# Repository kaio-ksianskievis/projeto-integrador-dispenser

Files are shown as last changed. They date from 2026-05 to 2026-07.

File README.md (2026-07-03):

# 🚰 Precision Water Dispenser - IoT Edition

> **Projeto Integrador - Engenharia da Computação (UFSM)**

Sistema de controle e gestão de dispenser de precisão operando de forma autônoma. O projeto utiliza um **ESP32** atuando como Web Server embutido (Edge Computing), hospedando sua própria interface de usuário e controlando o hardware em tempo real sem a necessidade de um servidor back-end externo.

---

## Testes e Calibração da Bomba

Para garantir a precisão do dispenser, realizamos testes práticos variando a tensão e medindo o tempo de resposta da bomba. Os dados coletados de vazão, corrente e tempo estão consolidados na tabela abaixo:

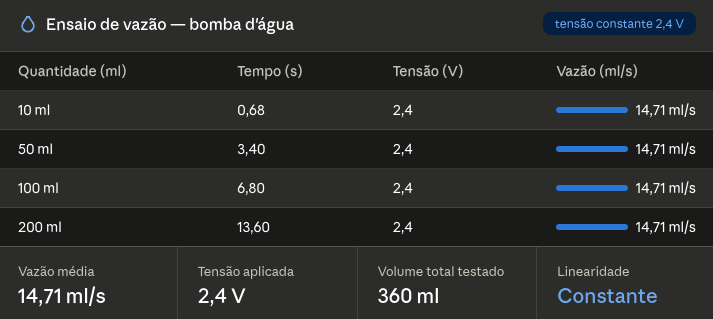
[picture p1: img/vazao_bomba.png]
Tabela de Calibração de Vazão


> **Nota de Engenharia:** Com base nesses testes, optamos por fixar a operação na tensão mínima de **2.4V** utilizando um módulo conversor Buck. Nessa faixa, a vazão oferece a melhor resolução para a matemática de controle de tempo no nosso firmware C++, minimizando o erro por inércia do motor e evitando transbordamentos.

---

## 📋 Sobre o Projeto

Este projeto foi arquitetado com foco na estabilidade elétrica e independência de rede, características essenciais para sistemas embarcados em apresentação.

### Principais Funcionalidades
* **Web Server Embutido:** A interface (HTML/CSS/JS) é hospedada diretamente na memória Flash do ESP32 utilizando `PROGMEM`, garantindo baixa latência e dispensando hospedagem externa.
* **Cálculo Dinâmico de Vazão:** O usuário insere a quantidade em mililitros (ml) via interface Web, e o JavaScript realiza a conversão em tempo de acionamento do relé com base no fator de calibração prático.
* **Isolação de Domínios de Energia:** Arquitetura de hardware projetada para isolar a alimentação do microcontrolador (5V lógico) da alimentação de força motriz (Bateria/Pilhas reguladas via LM2596), prevenindo resets por *brownout* devido ao pico de partida do motor.

---

## 🛠️ Stack Tecnológica

### Software (Firmware e Interface)
* **Linguagem Principal:** C/C++ (Arduino Core para ESP32)
* **Bibliotecas:** `WiFi.h`, `WebServer.h`
* **Front-end:** HTML5, CSS3, Vanilla JavaScript (Embutidos no C++)

### Hardware
* **Microcontrolador:** ESP32 (DevKit V1 / WROOM-32)
* **Atuador:** Bomba de Água RS 385 (Diafragma)
* **Chaveamento:** Módulo Relé 5V (1 Canal)
* **Regulação de Força:** Módulo Step-Down LM2596
* **Alimentação:** Fonte USB 5V (ESP32) + Suporte Independente de 4 Pilhas AA / Bateria de Lítio (Bomba)

---

## 🔧 Como Executar (Setup)

### 1. Montagem do Hardware (Atenção à Isolação)
Para reproduzir o projeto sem travamentos, respeite a separação de energia:
1. Conecte o **ESP32** na tomada via cabo USB (Pino `VIN` e `GND` alimentam a lógica do Relé).
2. Conecte a fonte de baterias isolada na entrada (`IN+` / `IN-`) do **LM2596**. Regule a saída para **2.4V**.
3. Use o pino **COM** e **NO** do Relé para chavear apenas o polo positivo que sai do LM2596 para a Bomba de Água. O `GND` da saída do LM2596 vai direto para a bomba.
4. O pino de sinal (`IN`) do Relé vai ao pino Digital `D4` do ESP32.

### 2. Configuração do Firmware
1. Abra o arquivo `.ino` ou `main.cpp` na IDE (Arduino IDE / PlatformIO).
2. Localize as variáveis de rede e insira as credenciais de um **Hotspot Móvel (2.4 GHz)** para contornar bloqueios de redes institucionais corporativas:
   ```cpp
   const char* ssid = "NOME_DO_SEU_HOTSPOT";
   const char* password = "SENHA";

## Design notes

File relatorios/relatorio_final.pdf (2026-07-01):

Dispenser de Líquidos — Relatório Final

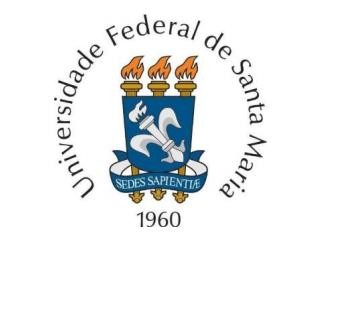
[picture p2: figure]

UNIVERSIDADE FEDERAL DE SANTA MARIA
Engenharia de Computação

# RELATÓRIO FINAL

## DISPENSER DE LÍQUIDOS

Sistema Automatizado de Dosagem com Controle Microcontrolado e Interface Web

Pedro Gomes
Leonardo Miotti
Breno Germano
Kaio Ksianskievis

Santa Maria, RS
2026

## 1. Introdução

Este documento consolida o relatório final do projeto Dispenser de Líquidos, desenvolvido pela equipe para a disciplina de Projeto Integrador do curso de Engenharia de Computação da UFSM. O trabalho evoluiu de uma proposta conceitual — um sistema automatizado de dosagem baseado no microcontrolador ESP32 — para um protótipo físico efetivamente montado, testado e ajustado em bancada.

Ao longo da implementação prática, diversas premissas do projeto original precisaram ser revistas a partir de evidência experimental: o componente hidráulico inicialmente escolhido não atendeu ao requisito de estanqueidade, e a topologia de alimentação elétrica planejada mostrou-se eletricamente inviável diante da corrente exigida pelos atuadores. Este relatório apresenta, de forma estruturada, o problema abordado, a solução proposta, o desenvolvimento realizado — incluindo as falhas técnicas identificadas e as respectivas ações corretivas — e os resultados obtidos até o momento.

## 2. Definição do Problema

O problema central reside na imprecisão e na falta de controle volumétrico em processos manuais de distribuição de líquidos. Em diversos contextos — desde o preparo de bebidas em escala comercial até o fracionamento de reagentes em laboratórios ou de insumos na agroindústria — a manipulação humana está sujeita a variações significativas (erro humano), o que resulta em desperdício de matéria-prima e falta de padronização no produto final.

Além disso, a ausência de monitoramento digital impede a coleta de dados sobre o consumo em tempo real. Sem uma interface de controle, torna-se inviável estabelecer dosagens exatas de forma repetitiva ou integrar essa tarefa a um ecossistema de Internet das Coisas (IoT), limitando a eficiência operacional e a rastreabilidade do processo.

Pontos-chave do problema:

- Variabilidade volumétrica: dificuldade em manter constância nas doses servidas manualmente.
- Ineficiência operacional: tempo gasto em medições manuais e retrabalho por erro.
- Falta de conectividade: inexistência de dados sobre o fluxo e o volume dispensado para fins de gestão e rastreabilidade.

## 3. Solução Proposta

A solução proposta consiste no desenvolvimento de um Sistema Automatizado de Dosagem com Controle Microcontrolado e Interface Web, fundamentado na integração de hardware e software para garantir precisão e facilidade de uso.

### 3.1. Arquitetura de Hardware

O núcleo do hardware é baseado no microcontrolador ESP32, escolhido por sua capacidade de processamento e conectividade Wi-Fi nativa. Ele é responsável por acionar a bomba dispensadora e por temporizar/medir a vazão de forma a garantir a dose exata configurada pelo usuário.

### 3.2. Arquitetura de Software

Para que a solução fosse completa e gerenciável, a arquitetura de software foi planejada em duas camadas, mantendo a proposta enxuta e compatível com o escopo da disciplina:

- Camada de Controle (Firmware): desenvolvida para o ESP32, responsável por gerenciar os periféricos de entrada e saída (sensores e atuadores) e por expor os comandos de dosagem através de requisições HTTP.
- Camada de Interface (HTML/CSS/JavaScript): interface web leve, servida diretamente pelo ESP32, que permite ao usuário selecionar a quantidade desejada e iniciar remotamente o processo de dosagem, sem a necessidade de um servidor de backend dedicado.

Optou-se por não utilizar uma camada de backend separada (como um servidor Java): a lógica de configuração de dose e o acionamento da bomba são tratados diretamente pelo firmware do ESP32, que também hospeda a página de interface. Essa simplificação reduziu a complexidade de integração e de infraestrutura necessária, mantendo o sistema autocontido em um único dispositivo.

### 3.3. Viabilidade Acadêmica

Essa abordagem é altamente viável para o contexto acadêmico, pois permite a aplicação de conceitos de Sistemas Operacionais de Tempo Real (RTOS), protocolos de comunicação (HTTP) e Engenharia de Software. O desenvolvimento foi planejado de forma modular: controle básico da bomba, seguido pela exposição de comandos via requisições HTTP e, por fim, a interface web em HTML/CSS/JavaScript — garantindo entrega contínua ao longo da disciplina.

## 4. Desenvolvimento Realizado

A fase de montagem e testes práticos do subsistema hidráulico e do subsistema de potência revelou necessidades de ajustes mecânicos e eletrônicos essenciais para o funcionamento correto e seguro do dispositivo. Esta seção descreve, de forma técnica, cada etapa da implementação, os problemas identificados e as ações corretivas adotadas.

### 4.1. Subsistema Hidráulico: Seleção e Substituição da Bomba

Nos testes funcionais de bancada para homologação dos atuadores, a equipe montou e avaliou operacionalmente uma motobomba submersível/in-line (Bomba 1). Os ensaios práticos revelaram uma inconformidade crítica no comportamento dinâmico do fluido: após o corte da alimentação elétrica do motor, o componente falhou em interromper o fluxo ("não parava a água"). Essa ausência de estanqueidade passiva gerava gotejamento contínuo e fluxo residual por gravidade/sifonagem, o que comprometia totalmente o requisito de precisão volumétrica do dispenser.

Diante desse comportamento inadequado, a estrutura original foi desmontada para avaliação técnica. Como ação corretiva, para assegurar o bloqueio imediato do fluido, o dispositivo foi readequado com uma bomba eletrônica dispensadora (Bomba 2), componente que apresentou o comportamento esperado nos testes práticos, retendo o fluido com sucesso e garantindo a repetibilidade das doses configuradas pelo sistema.

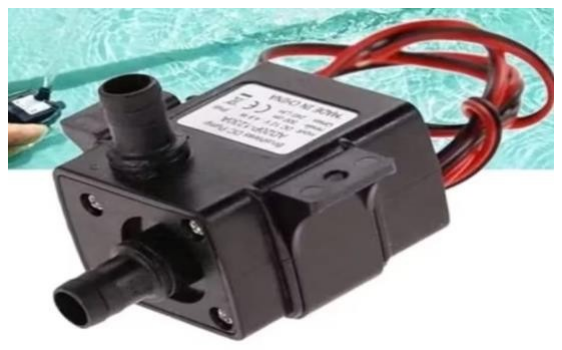
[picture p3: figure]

Figura 1 — Bomba 1: motobomba submersível/in-line (descartada).

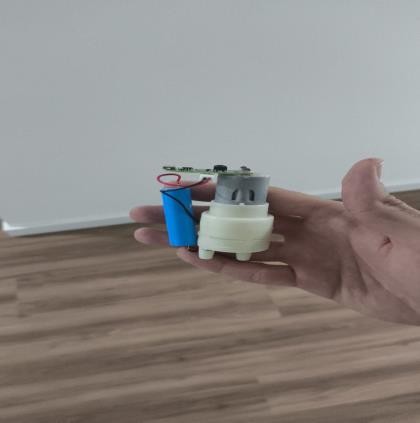
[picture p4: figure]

Figura 2 — Bomba 2: bomba eletrônica dispensadora (adotada).

### 4.2. Calibração e Caracterização da Bomba

Para garantir a precisão do dispenser, foram realizados testes práticos variando a tensão aplicada e medindo o tempo de resposta da bomba para diferentes volumes-alvo. Os dados de vazão, tensão e tempo estão consolidados na tabela a seguir:

Quantidade (ml) | Tempo (s) | Tensão (V) | Vazão (ml/s)
10 ml | 0,68 | 2,4 | 14,71
50 ml | 3,40 | 2,4 | 14,71
100 ml | 6,80 | 2,4 | 14,71
200 ml | 13,60 | 2,4 | 14,71

Resultado: vazão média de 14,71 ml/s sob tensão constante de 2,4 V, com volume total testado de 360 ml e comportamento linear/constante em toda a faixa avaliada (10 a 200 ml). Esse resultado validou o ponto de operação de 2,4 V como referência de tensão para a bomba nas etapas seguintes do projeto.

### 4.3. Subsistema de Alimentação Elétrica — Concepção Original

Para garantir a estabilidade elétrica do microcontrolador e dos atuadores de forma isolada e contínua, o projeto original previa uma fonte portátil baseada em bateria de íon-lítio, com a seguinte cadeia de componentes operando em cascata:

- Uma bateria de íon-lítio como fonte primária de energia;
- Um módulo carregador/protetor TP4056, responsável por gerenciar a carga da bateria;
- Um módulo elevador de tensão (step-up/boost), responsável por elevar a tensão da célula (~3,7 V nominal) até um barramento fixo e estabilizado de 5 V, utilizado para alimentar o ESP32 e o ecossistema interno;
- Um conversor DC-DC abaixador (step-down) LM2596, conectado subsequentemente ao barramento de 5 V, com a função de reduzir a tensão para os 2,4 V fixos exigidos pela bomba dispensadora, validados na etapa de calibração (seção 4.2).

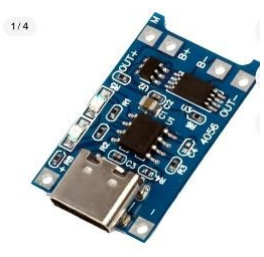
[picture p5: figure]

Figura 3 — Módulo carregador/protetor TP4056 (removido da topologia final).

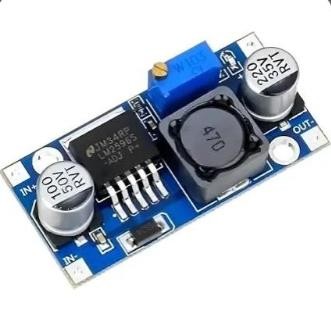
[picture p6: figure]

Figura 4 — Conversor DC-DC Step-Down LM2596 (mantido na topologia final).

### 4.4. Falha do Subsistema de Alimentação: Diagnóstico Técnico

Durante a integração da bomba dispensadora ao subsistema de potência descrito na seção 4.3, a equipe identificou que a cadeia bateria de íon-lítio → TP4056 → módulo elevador de tensão não era capaz de fornecer corrente suficiente para alimentar simultaneamente o ESP32 e a bomba. Trata-se de um problema de orçamento de corrente (current budget), e não de tensão: cada um dos dois módulos removidos — o carregador/protetor TP4056 e o conversor elevador de tensão — é dimensionado, em módulos comerciais compactos como os utilizados, para correntes contínuas e de pico relativamente baixas, tipicamente adequadas para alimentar cargas eletrônicas leves (como o próprio ESP32 em regime normal).

A bomba eletrônica dispensadora (Bomba 2), por sua vez, é um atuador com demanda de corrente elevada em relação a esses módulos, sobretudo no instante de acionamento (corrente de partida/estabelecimento de fluxo). Quando bomba e ESP32 foram conectados ao mesmo barramento derivado da célula de lítio, a corrente total solicitada excedeu a capacidade de fornecimento da cadeia carregador + elevador de tensão, provocando queda de tensão no barramento compartilhado incompatível com a operação estável de ambos os dispositivos simultaneamente. Em outras palavras, a fonte projetada para portabilidade não possuía margem de corrente suficiente para sustentar a carga combinada do microcontrolador (com picos de consumo durante transmissão Wi-Fi) e do atuador hidráulico.

Esse resultado é relevante porque compromete diretamente o requisito central do projeto — a precisão e repetibilidade da dosagem — já que instabilidade de tensão na alimentação da bomba afeta a vazão efetiva, e instabilidade no barramento do microcontrolador compromete a temporização/controle que determina o volume dispensado.

### 4.5. Ação Corretiva: Reestruturação da Topologia de Alimentação

Como ação corretiva, a equipe optou por abandonar por completo a bateria de íon-lítio, o módulo carregador TP4056 e o módulo elevador de tensão, mantendo na topologia apenas o conversor abaixador LM2596. A solução adotada consistiu em separar fisicamente os dois domínios de alimentação, eliminando a disputa por corrente entre os dispositivos:

- Domínio do ESP32: o microcontrolador passou a ser alimentado diretamente pela tomada/USB do computador — uma fonte externa regulada, com margem de corrente muito superior à necessária, e imune a variações de carga causadas pelo acionamento da bomba.
- Domínio da bomba: a bomba passou a ser alimentada por um conjunto de pilhas (fonte primária descartável, com capacidade de fornecimento de corrente adequada ao atuador), conectado ao conversor LM2596, regulando a tensão para o mesmo ponto de operação de 2,4 V já validado na etapa de calibração — preservando, assim, a vazão média medida de 14,71 ml/s.

Ao desacoplar os dois domínios elétricos, cada fonte passou a alimentar apenas uma carga, o que eliminou o problema de orçamento de corrente identificado na seção 4.4. Essa mudança tem como custo a perda de portabilidade total do protótipo nesta etapa (o ESP32 depende de uma fonte USB externa próxima), o que é registrado como limitação a ser endereçada em trabalhos futuros (seção 6).

Componente | Topologia Original | Topologia Final (adotada)
Fonte primária | Bateria de íon-lítio | Pilhas (bomba) + USB do PC (ESP32)
Carregador/proteção | Módulo TP4056 | Removido
Elevador de tensão (boost) | Módulo step-up para 5 V | Removido
Abaixador de tensão (buck) | LM2596 (5 V → 2,4 V) | LM2596 (pilhas → 2,4 V)
Alimentação do ESP32 | Barramento de 5 V compartilhado | USB/tomada do computador (domínio isolado)
Alimentação da bomba | Barramento de 2,4 V compartilhado | Pilhas + LM2596 (domínio isolado)

### 4.6. Integração de Software

As modificações de hardware descritas nas seções anteriores foram tratadas como pré-requisito para a etapa de software: sem um subsistema elétrico estável, qualquer firmware de controle de tempo/vazão estaria sujeito a resets e leituras inconsistentes. Com a topologia de alimentação corrigida, os próximos passos de desenvolvimento de software — detalhados na seção 6 — passam a ter uma base elétrica confiável para serem implementados e validados.

## 5. Resultados Obtidos

A partir dos testes de bancada realizados, os seguintes resultados foram obtidos:

- Estanqueidade do sistema hidráulico: a substituição da Bomba 1 pela Bomba 2 eliminou o fluxo residual por gravidade/sifonagem, atendendo ao requisito de bloqueio imediato do fluido ao final da dosagem.
- Caracterização de vazão: vazão média de 14,71 ml/s sob 2,4 V, com comportamento constante e linear em toda a faixa de volumes testada (10 a 200 ml), confirmando a viabilidade de calcular o tempo de acionamento necessário para qualquer dose dentro dessa faixa.
- Diagnóstico e correção do subsistema de alimentação: identificação da limitação de corrente da cadeia bateria de íon-lítio + TP4056 + boost, e validação prática de uma topologia alternativa com domínios de alimentação independentes (USB para o ESP32; pilhas + LM2596 para a bomba), eliminando a queda de tensão observada anteriormente.
- Montagem física do protótipo: integração dos componentes eletrônicos (bomba, conversor LM2596, porta-pilhas, ESP32 e conexões de mangueira) em uma estrutura de suporte, incluindo peças auxiliares, conforme registrado nas figuras 5 e 6.

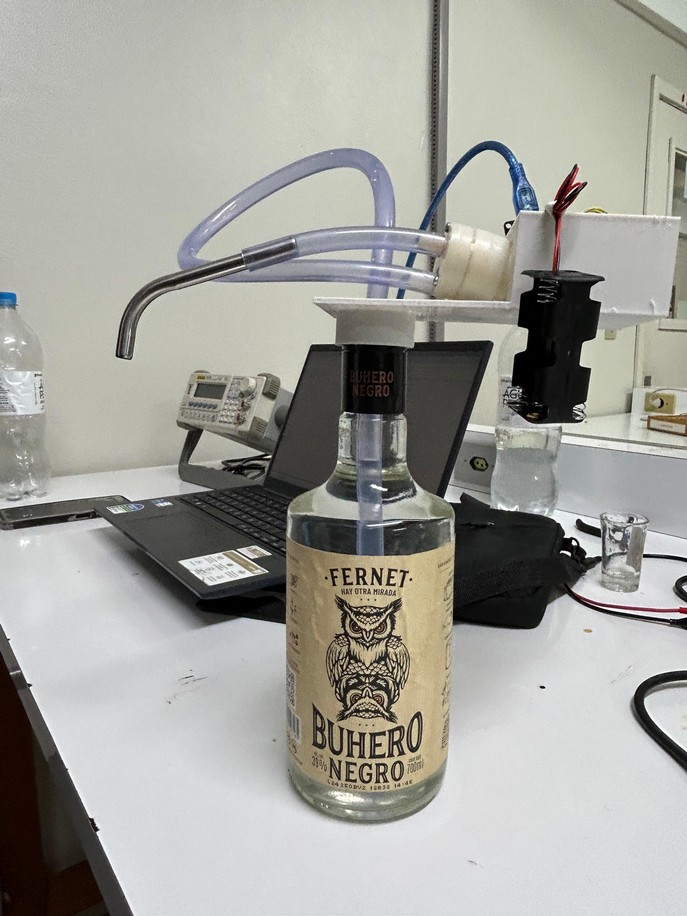
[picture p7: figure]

Figura 5 — Protótipo montado em bancada, acoplado a uma garrafa para teste de dosagem.

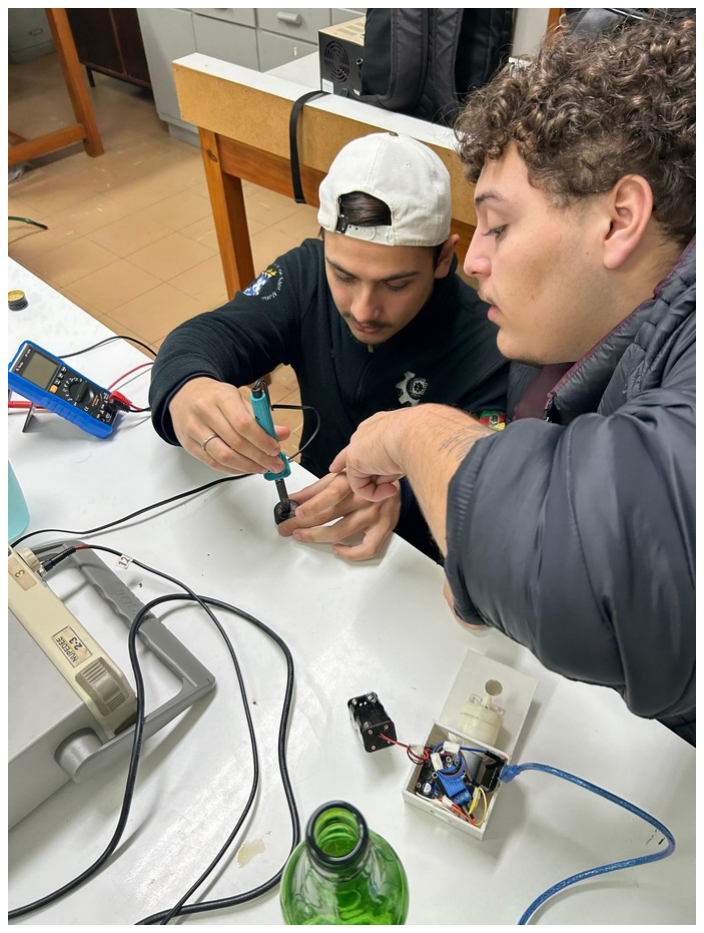
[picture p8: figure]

Figura 6 — Equipe durante a montagem/solda dos componentes eletrônicos do dispenser.

Como limitações ainda em aberto, destacam-se: (i) a dependência de uma fonte USB externa para o ESP32, o que reduz a portabilidade do protótipo; (ii) o firmware de controle de tempo/vazão ainda requer refinamento sob a nova estrutura elétrica; e (iii) a interface web em HTML/CSS/JavaScript permanece pendente de implementação e integração completas com o firmware.

## 6. Conclusão e Próximos Passos

As modificações executadas ao longo da fase prática evidenciam uma abordagem de engenharia iterativa — testar, diagnosticar, corrigir — que vai além de um protótipo conceitual rudimentar. Tanto a falha hidráulica (Bomba 1) quanto a falha elétrica (cadeia bateria/TP4056/boost) foram identificadas por meio de ensaios de bancada, analisadas tecnicamente e corrigidas com soluções validadas experimentalmente, ainda que às custas de simplificações momentâneas (como a dependência de fonte USB externa).

Os próximos passos do desenvolvimento incluem:

- Refinamento do firmware de controle de tempo/vazão no ESP32 sob a nova estrutura elétrica estável;
- Estabelecimento e consolidação das requisições HTTP entre a interface web e o firmware do ESP32;
- Validação final da interface de usuário, desenvolvida em HTML/CSS/JavaScript e servida diretamente pelo ESP32;
- Avaliação de uma solução de alimentação portátil para o ESP32 (por exemplo, bateria dedicada com maior capacidade de corrente contínua, ou reguladores independentes por domínio de carga), de modo a eliminar a dependência atual de fonte USB externa sem reintroduzir o problema de orçamento de corrente identificado na seção 4.4.

## 7. Repositório do Projeto

O código-fonte do firmware desenvolvido para o ESP32 está disponível no repositório do projeto:

https://github.com/kaio-ksianskievis/projeto-integrador-dispenser/tree/main/esp32

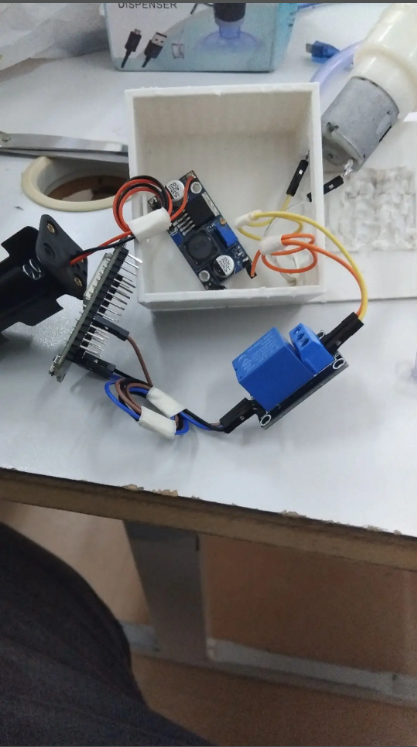
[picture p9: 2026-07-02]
img/Hardware_do_Projeto.png

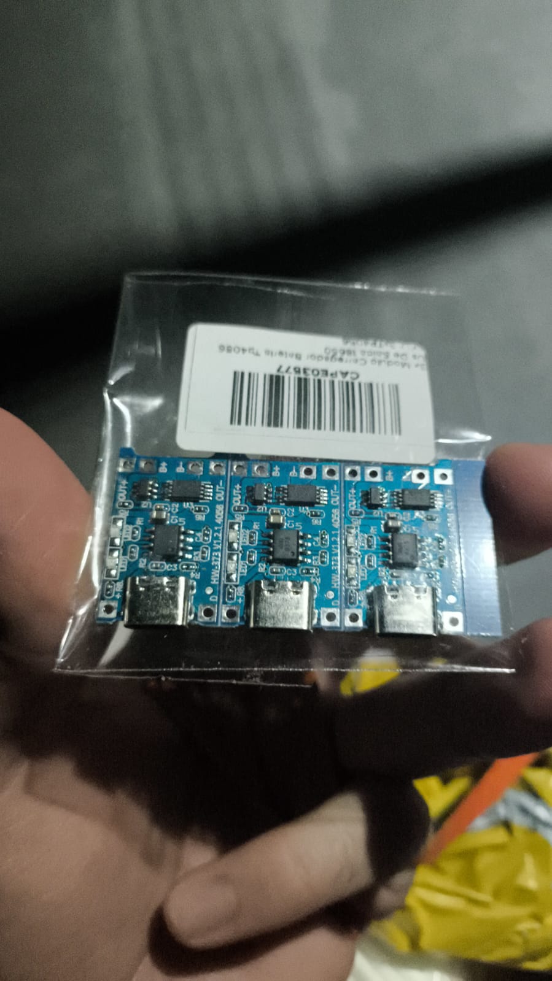
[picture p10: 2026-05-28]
img/Modulo Carregador Bateria Tp4056.jpeg

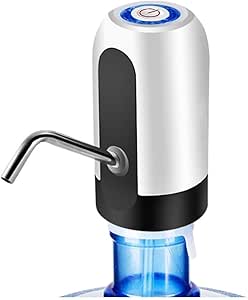
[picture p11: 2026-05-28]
img/bomba d'agua inteira.jpg

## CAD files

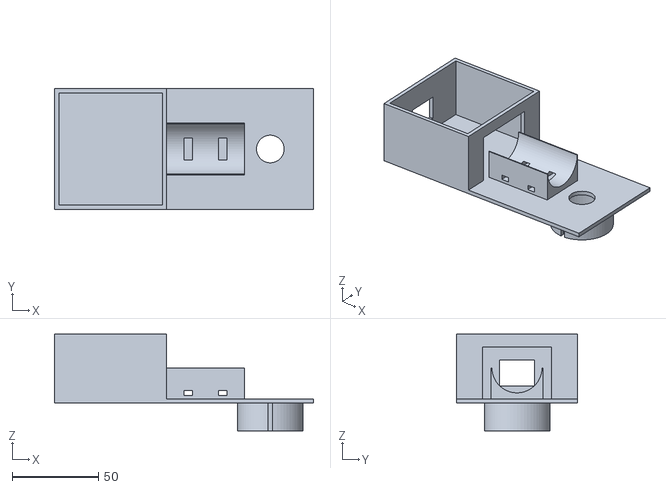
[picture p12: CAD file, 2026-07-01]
modelo 3D/trabalho_bomba.stl
150.0 x 70.0 x 56.0

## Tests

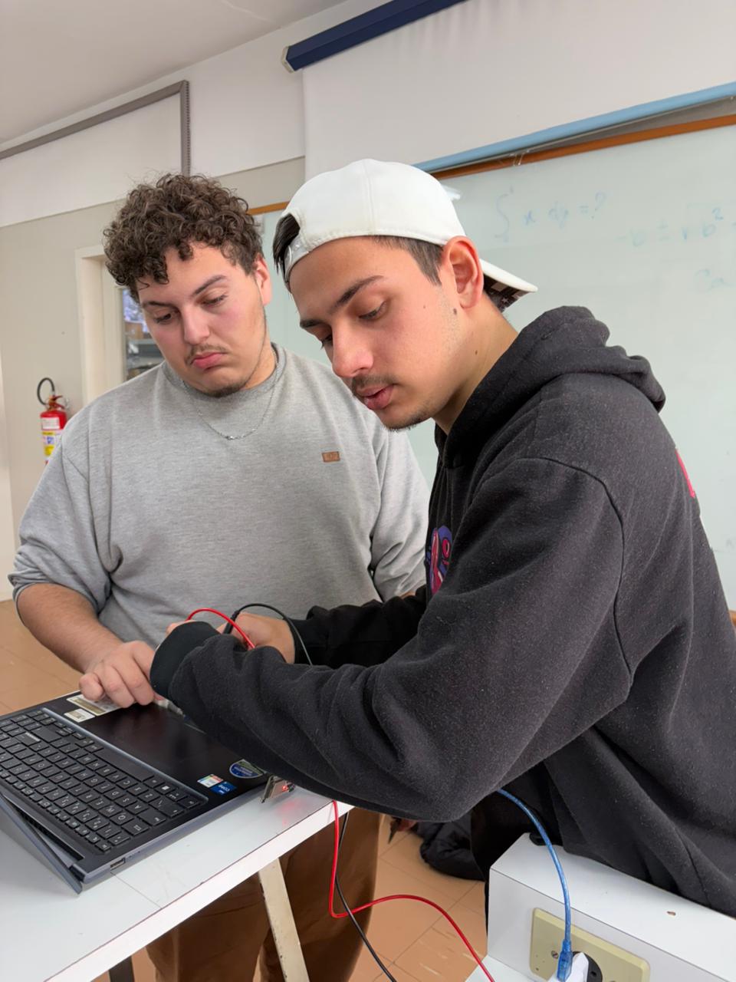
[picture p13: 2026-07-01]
img/Testes1.jpeg

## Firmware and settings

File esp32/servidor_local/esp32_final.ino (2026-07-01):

#include <WiFi.h>
#include <WebServer.h>
#include "soc/soc.h"           
#include "soc/rtc_cntl_reg.h"  

// Coloque o nome da sua rede e senha aqui
const char* ssid = "IOT_CT"; 
const char* password = "1@T_ct2023";      

WebServer server(80);
const int RELAY_PIN = 4;

void setup() {
  // 1. Desativa o alarme de queda de tensão
  WRITE_PERI_REG(RTC_CNTL_BROWN_OUT_REG, 0); 
  
  Serial.begin(115200);
  
  pinMode(RELAY_PIN, OUTPUT);
  digitalWrite(RELAY_PIN, LOW); 

  Serial.println("\nIniciando conexão Wi-Fi...");

  // Isso impede o pico de corrente que está reiniciando o seu notebook.
  WiFi.setTxPower(WIFI_POWER_8_5dBm);

  WiFi.begin(ssid, password);

  // Fica aguardando conectar
  while (WiFi.status() != WL_CONNECTED) {
    delay(500);
    Serial.print(".");
  }

  Serial.println("\n=================================");
  Serial.println("Conexão Wi-Fi estabelecida!");
  Serial.print("COPIE ESTE IP: ");
  Serial.println(WiFi.localIP());
  Serial.println("=================================");

  // 3. Rota do servidor para ligar a bomba
  server.on("/bomba", HTTP_GET, []() {
    server.sendHeader("Access-Control-Allow-Origin", "*");

    if (server.hasArg("tempo")) {
      String tempoParam = server.arg("tempo");
      unsigned long tempoEnchimento = tempoParam.toInt();

      Serial.print("Comando recebido! Acionando por: ");
      Serial.print(tempoEnchimento);
      Serial.println(" ms");

      digitalWrite(RELAY_PIN, HIGH);
      delay(tempoEnchimento);
      digitalWrite(RELAY_PIN, LOW);

      server.send(200, "text/plain", "Bomba acionada com sucesso");
    } else {
      server.send(400, "text/plain", "Faltou informar o tempo");
    }
  });

  server.begin();
  Serial.println("Servidor Web rodando e aguardando comandos.");
}

void loop() {
  server.handleClient();
}

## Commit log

2026-05-16 Adicionando tabela de valores de vazão da nossa bomba
2026-05-16 Add testing and calibration section to README
    Added a section on testing and calibration of the dispenser pump, including practical tests and data consolidation.
2026-05-27 Adicionando código inicial da esp32
2026-07-01 adicionando arquivos da esp32
2026-07-01 adicionando modelo 3D
    [trabalho_bomba.stl]
2026-07-03 atualizando tabela de valores de vazão
